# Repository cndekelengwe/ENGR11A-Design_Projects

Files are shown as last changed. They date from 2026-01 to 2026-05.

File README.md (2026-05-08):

# Automatic Pill Dispenser
## Overview 
**Possible limits: Needing a 3D Printer and Soldering machine** 

Our project addresses the challenge that older adults with dementia or memory-related conditions face when trying to manage their medications independently. Many struggle to remember when to take their pills or whether they have already taken them, which can lead to missed doses or double-dosing. Based on this, our needs statement is that users require a system that not only organizes their medication clearly but also supports them in taking the correct pills at the correct time without relying heavily on a caregiver. To guide our design, we focused on three main principles: simplicity, reliability, and automation. The device must be easy to understand and use, consistently perform without errors, and reduce the need for memory through automated assistance. Success for our design would mean that the device can accurately stop at the correct compartment every time, dispense the correct pills, and remain easy for users to load and interact with. We plan to measure this through testing stopping accuracy, consistency over repeated rotations, and how easily a user can interact with the system. If the device does not meet these expectations, we will adjust key elements such as compartment spacing, magnet placement, or control logic to improve performance.

## Final Design Challenges and Lessons Learned

Our final CAD design aimed to create a rotating pill dispenser system similar to a Ferris wheel, where a circular 15-compartment wheel rotated inside a rectangular support structure. The design included 14 compartments for daily and nightly medication and one additional compartment serving as a refill or reminder section. To automate positioning, magnets were embedded into the rotating inner section, while Hall sensors connected to an Arduino system were intended to detect the magnets and stop the wheel at the correct compartment. The overall goal was to create a system that could reliably organize and dispense medication while supporting user independence and reducing medication errors.

However, during testing and evaluation of the final design, we encountered a major issue with the sensor-detection system. Because the wheel continuously rotated, the Hall sensors were not consistently able to detect every magnet as intended. Some magnets were detected successfully, while others were missed depending on alignment, spacing, and distance during rotation. This created an inconsistency in stopping accuracy, which reduced the reliability of the dispensing mechanism. As a result, although the design successfully demonstrated the overall concept and functionality of the system, the final STL design was not fully reliable in practice and would require additional redesign iterations before being used as a dependable automated dispenser.

One major lesson learned from this project was the importance of sensor placement and detection range in rotating automated systems. For future improvements, we would recommend using larger magnets and increasing the overall scale of the design to improve the consistency of Hall sensor detection. Increasing spacing and improving alignment tolerance between components would likely make the stopping mechanism more reliable and improve overall system performance.

Below are the STL files for the final design in case anyone would like to experiment with or improve upon the project further. We also made the different design iterations and cycles public so others can see the progression of the project from early concepts to the final design. All CAD files, iterations, and design changes can be found on Onshape through the link attached below. Onshape is free to use, making it accessible for anyone interested in viewing, modifying, or building upon the project.

[Rectangular Outlier Box File ](https://github.com/cndekelengwe/ENGR11A-Design_Projects/blob/main/pill_dispenser/Rectangular%20box.stl)  
[Wheel Compartements for pills STL File ](https://github.com/cndekelengwe/ENGR11A-Design_Projects/blob/main/pill_dispenser/cycle%203%20-%20Part%201%20(1).stl)  
[Drop box](https://github.com/cndekelengwe/ENGR11A-Design_Projects/blob/main/pill_dispenser/drop%20box%20-%20Part%201.stl)  
[ONshape Public File](https://cad.onshape.com/documents/309217a32cb4d046a7bca957/w/9944779888e9e89e632aefbe/e/01b1d22fc2a453b275cd808a)  (PS - if the link is unclickable, then copy the link and paste in the search bar) 

## Step-by-Step Circuit Assembly Guide for the Automatic Pill Dispenser
**Necessary Items** 

Download Arduino or any compatible coding platform for arduino board. 

A small breadboard (you can use basically any breadboard as long as it accommodates the necessary design size) 

A couple of different jumper wires - link

A USB Printer Cable

An LED (depending on how much light you want,  get as many LEDs).

A motor - Gebildet 8pcs DC3V-12V DC Geared Motor, for Aircraft Toys/Robotic Body/Four-Wheel Drive Toy Car, Batch Number: Double Axis 1:48

2 regular wires
A soldering machine is not needed, but is suggested; it is commonly found in a library. 

A cable to connect the battery 

Resistor (higher than 222 ohms) 

A 9V battery clip

DRV8833 Dual H-Bridge DC Motor Driver Module H

Link for Recommended Purchases - https://docs.google.com/document/d/1mJEsCzdOZILXJwwprC4P9GmpTi7Cr48AwGSw3bIJmXU/edit?tab=t.0 

**Step-By_Step Processs For Code and Circuit** 

1. For every Hall sensor, use male-to-female jumper wires to connect them to the Hall sensor and buzzer, remembering which wire colors go where (look at the picture for reference). <p align="center">
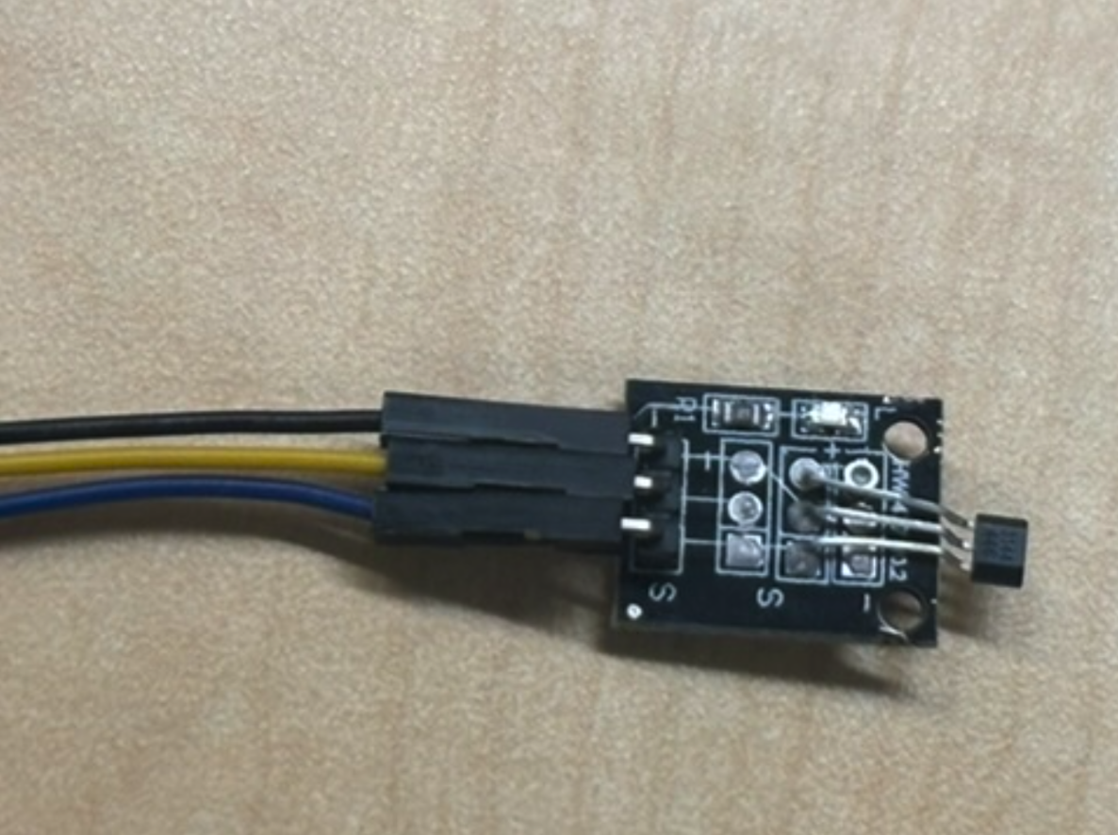
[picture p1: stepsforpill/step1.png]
   </p>
2. Now connect the blue jumper wire (or whatever color you used) to the corresponding pin numbers (2, 3, 4, 5), and connect the purple jumper wire (buzzer) to pin number 6.<p align="center">
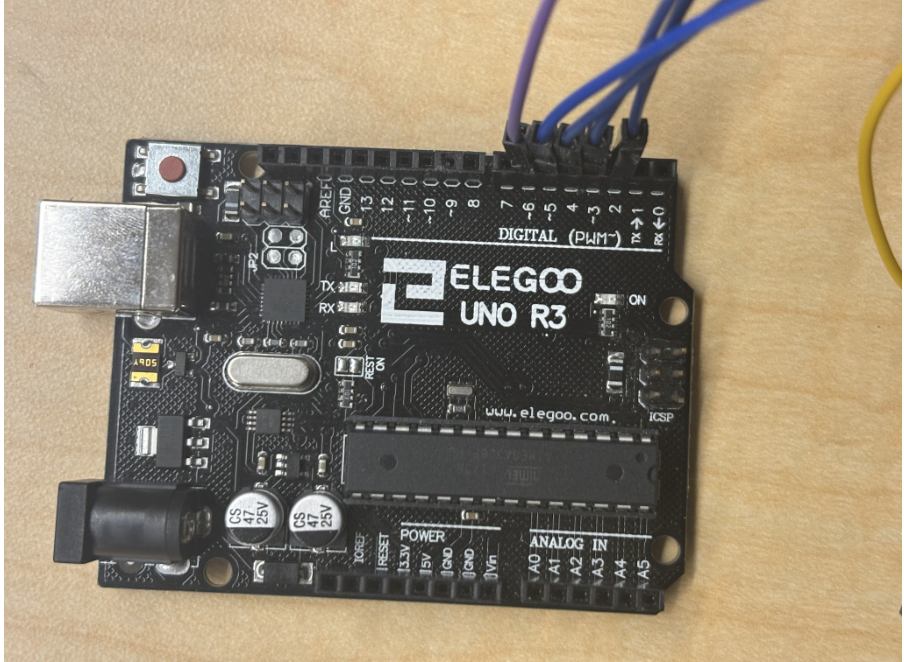
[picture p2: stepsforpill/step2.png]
   </p> 
3. Then, using the breadboard, align all the yellow jumper wires (power) on a single row and the black jumper wires (ground) on the row below.<p align="center">
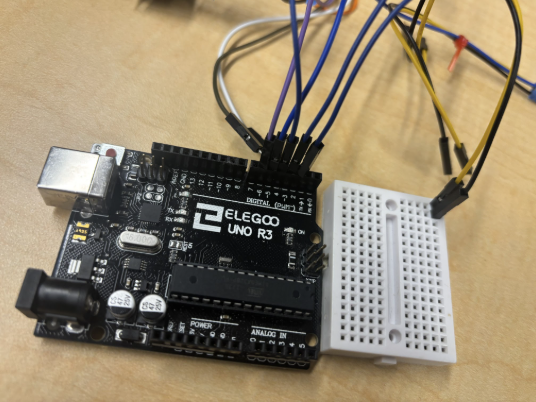
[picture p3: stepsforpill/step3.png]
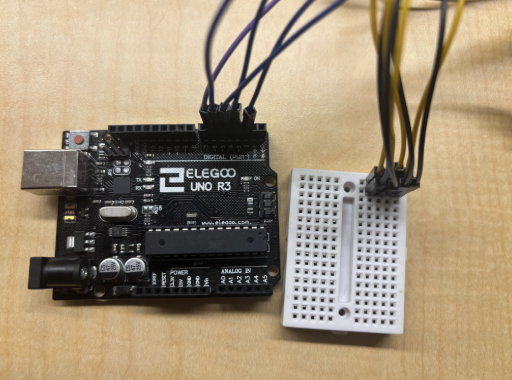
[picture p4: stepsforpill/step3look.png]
    </p>
4. If using the small breadboard, use two male-to-male wires to connect each row to the corresponding row next to it.<p align="center">
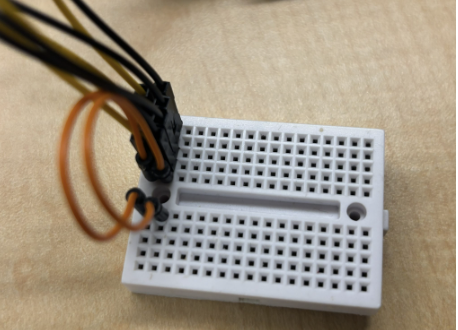
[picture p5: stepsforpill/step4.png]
   </p>
5. Then connect the corresponding buzzer cable to power and ground. (In this case, power was connected through a white jumper cable and ground through a brown cable.)<p align="center">
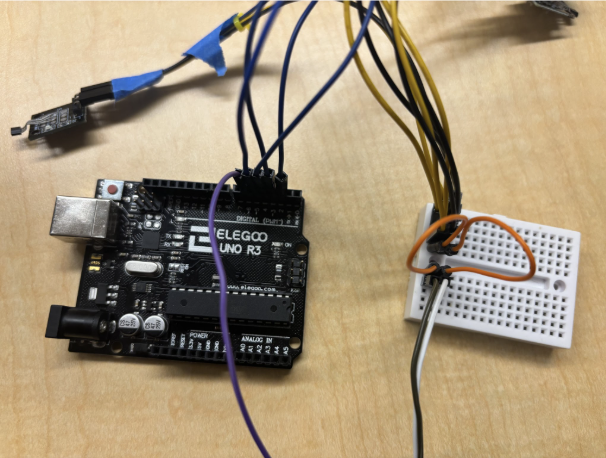
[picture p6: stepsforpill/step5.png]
   </p>
6. Next, use male-to-male wires to connect one wire from the 5V pin on the Arduino board to the power row on the breadboard. Then connect another wire from the GND pin on the Arduino board to the corresponding ground row on the breadboard. (Red is power and green is ground.)<p align="center">
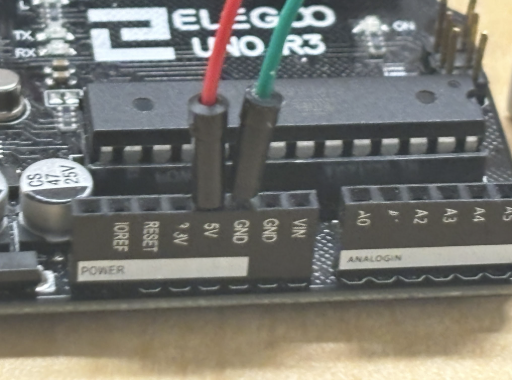
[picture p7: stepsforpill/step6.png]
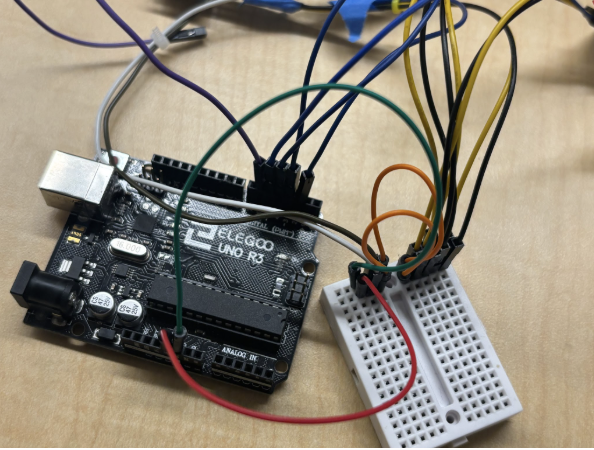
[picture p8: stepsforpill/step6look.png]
    </p>
7. Then move on to the Dual H-Bridge; connect IN1 and IN2 to the corresponding pin numbers on the Arduino board, which are pins 10 and 11. <p align="center">
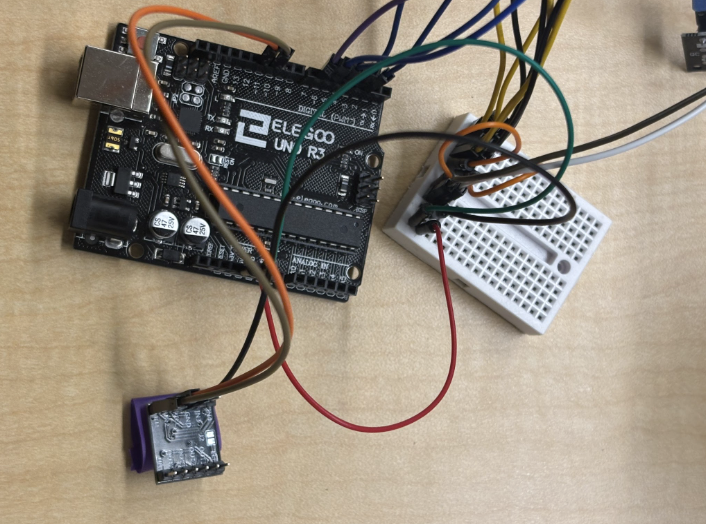
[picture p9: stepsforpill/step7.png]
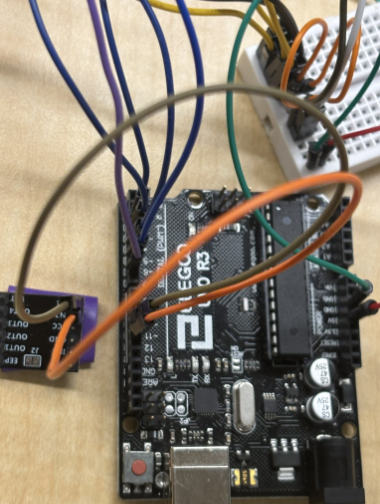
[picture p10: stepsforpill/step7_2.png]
    </p>
8. Using another male-to-female connector, connect GND from the Dual H-Bridge to one of the spaces on the GND row of the breadboard.
9. Then, using 2 wires, carefully strip part of the insulation and wrap the exposed wire around the small flaps at the tip of the motor wire. Bonus points if you solder them together for a stronger connection.<p align="center">
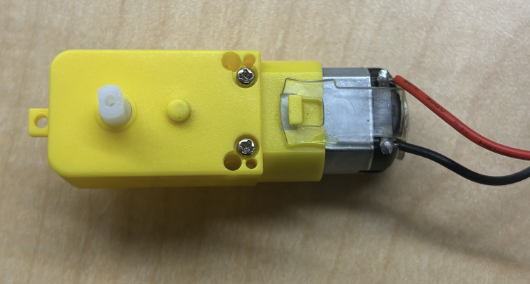
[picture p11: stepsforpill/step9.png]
   </p>
10. Then use two female-to-female wires to connect the wires to OUT1 and OUT2, connecting the motor to the circuit. (It does not matter which wire goes where; it only determines the direction the motor spins.)<p align="center">
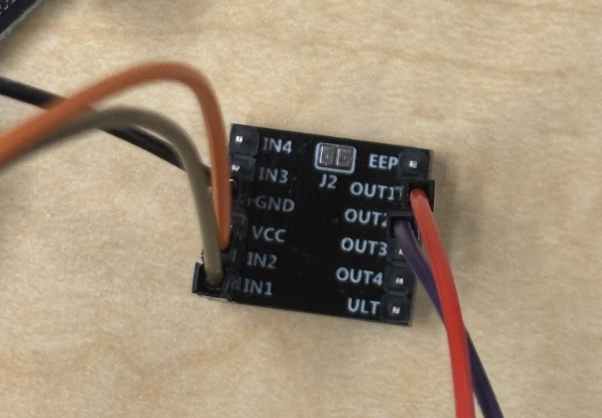
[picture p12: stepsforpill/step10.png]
    </p>
11. Use an additional male-to-male wire to connect the designated ground row on the breadboard to an additional row on the breadboard (look at the image for an example; it is the blue wire).<p align="center">
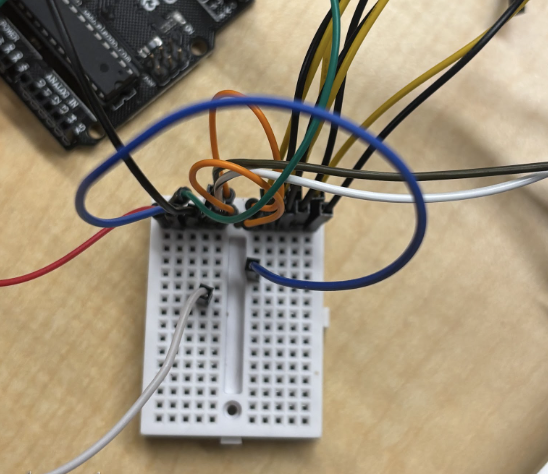
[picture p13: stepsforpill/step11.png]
   </p>
12. Then connect the black wire of the 9V battery clip to the row connected to the GND of the Arduino board.
13. Using a male-to-female connector, connect the pin labeled EEP on the breadboard, then connect the red wire from the battery clip to it. <p align="center">
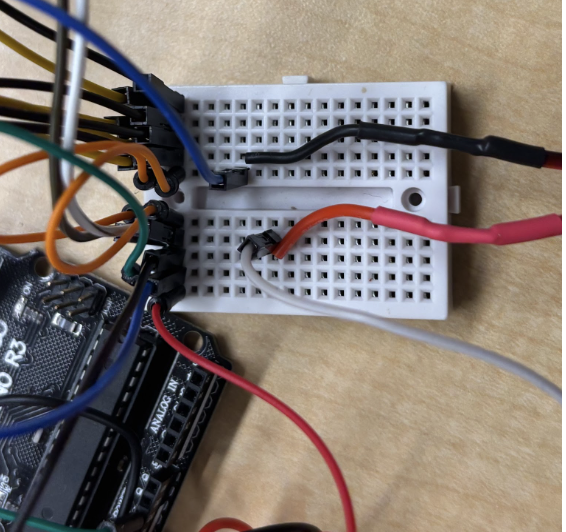
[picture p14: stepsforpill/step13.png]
   </p>
14. To connect the LED, use a male-to-male connector to connect the LED pin number (in this case, pin 13) to an empty row on the breadboard. (This allows multiple LEDs to share the same pin without requiring additional programming or extra pin numbers.) <p align="center">
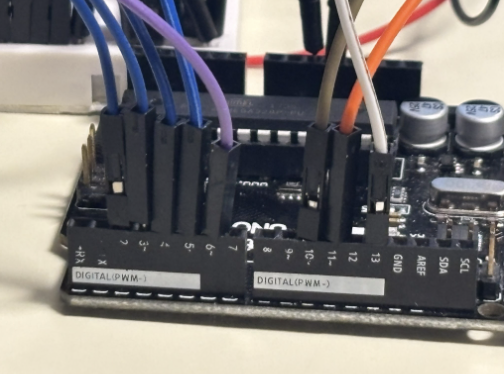
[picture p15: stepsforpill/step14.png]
   </p>
15. Connect both LED pins to male-to-female jumper wires, making sure to remember which wire is connected to which leg. This gives the LEDs more flexibility in placement. <p align="center">
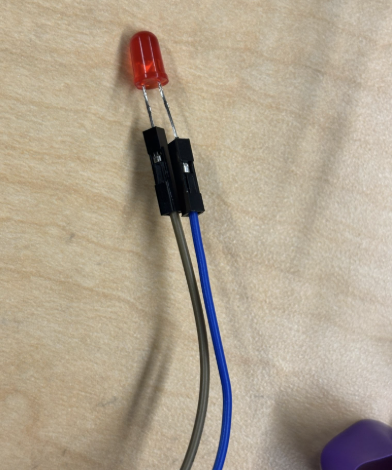
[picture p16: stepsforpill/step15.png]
   </p> In this case, the blue wire is the longer leg of the LED, and the black wire is the shorter leg.
16. Then take a resistor and place one leg of the resistor into the row connected to the LED pin number and the other leg into the designated ground row on the breadboard. <p align="center">
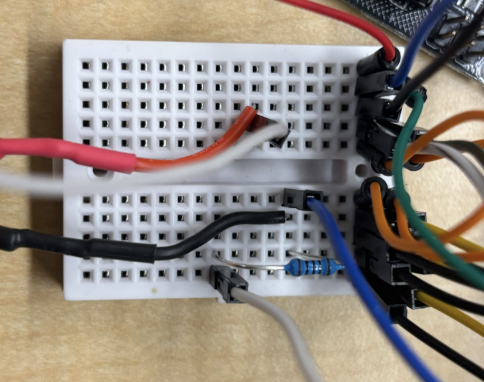
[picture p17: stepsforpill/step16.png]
   </p>
17. Finally, connect the LED to both the designated ground row and the LED row. Connect the shorter leg (cathode) to the GND row and the longer leg (anode) to the row connected to the LED pin number.
18. After completing all circuit connections, connect the Arduino board to a computer using a USB cable.
19. Open the Arduino IDE and upload the pill dispenser code to the Arduino board. Make sure the correct board type and COM port are selected before uploading. The board should be the same, but the port (circle in blue) depends on your computer <p align="center">
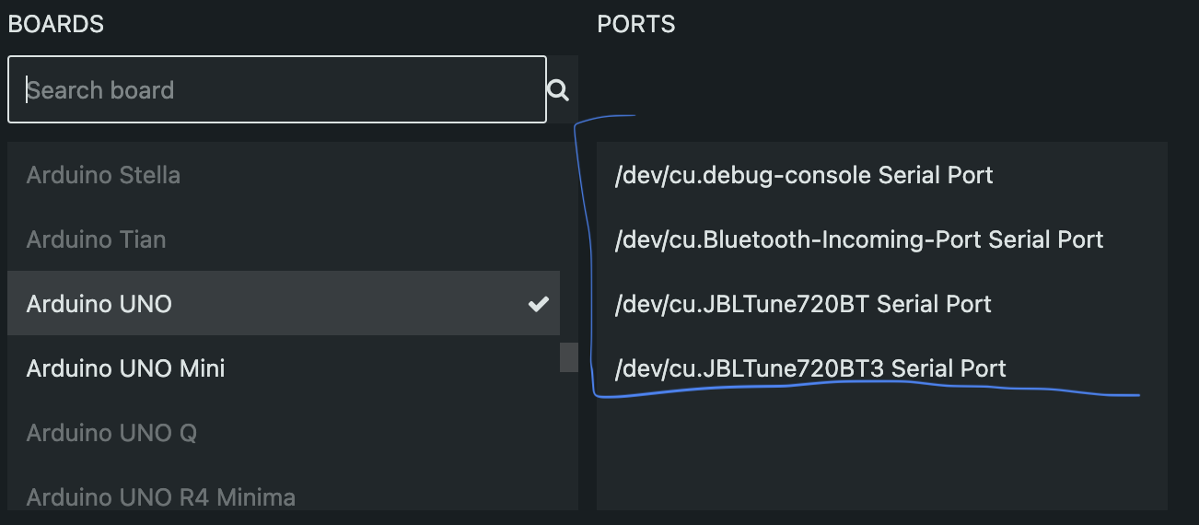
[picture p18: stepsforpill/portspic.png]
   </p>
20. Connect the 9V battery to the battery clip to power the system (for the H-board). The Hall sensors, LEDs, buzzer, and motor should now receive power through the circuit. (PS - in the complete picture, the blue drawing shows where the first battery connecting to the H-board goes) 
21. Test the system by checking whether the Hall sensors correctly detect the magnets and stop the motor at the intended compartment positions. Also, verify that the LEDs and buzzer respond correctly. PS - the motor should always be spinning, stop when it sees a magnet, which is followed by the buzzer and LED lighting. Then, depending on the time chosen (the default time being 20 seconds), it will start spinning after that.
22. If the system does not behave as expected, recheck all wiring connections, sensor alignment, magnet placement, and uploaded code. Small changes in spacing or alignment may significantly affect Hall sensor detection accuracy.
23. Once the system works as needed, disconnect the Arduino board from the computer. Plug in the second battery in the Arduino board. (PS - in the complete picture, the pink drawing shows where the second battery connecting to the Arduino board goes) 
24. Once testing is complete and the system functions correctly, secure loose wires and components to improve the stability and reliability of the final setup. <p align="center">
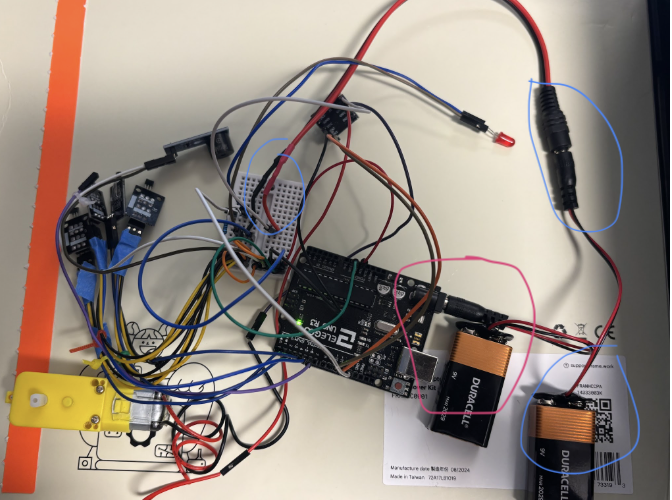
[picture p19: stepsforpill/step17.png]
   </p>

**Step-By_Step Processs For CAD with ONshape** 
1. Print the Final Cycle Outer Box <p align="center">
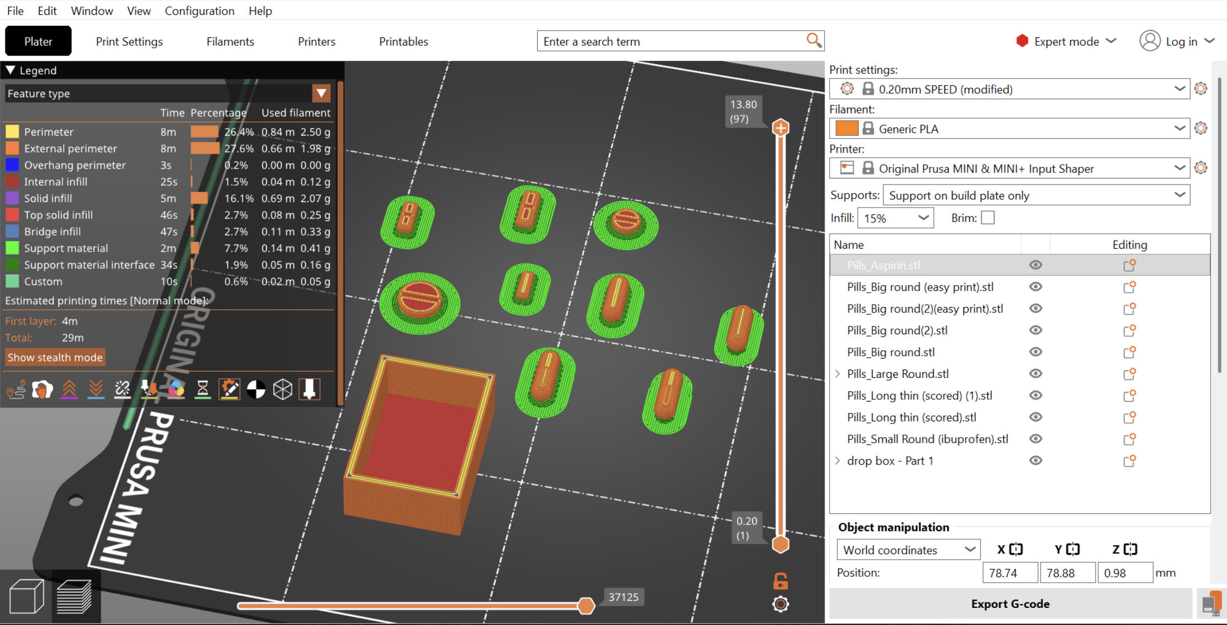
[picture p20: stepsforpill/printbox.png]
   </p>
2. Print the Final Cycle Wheel <p align="center">
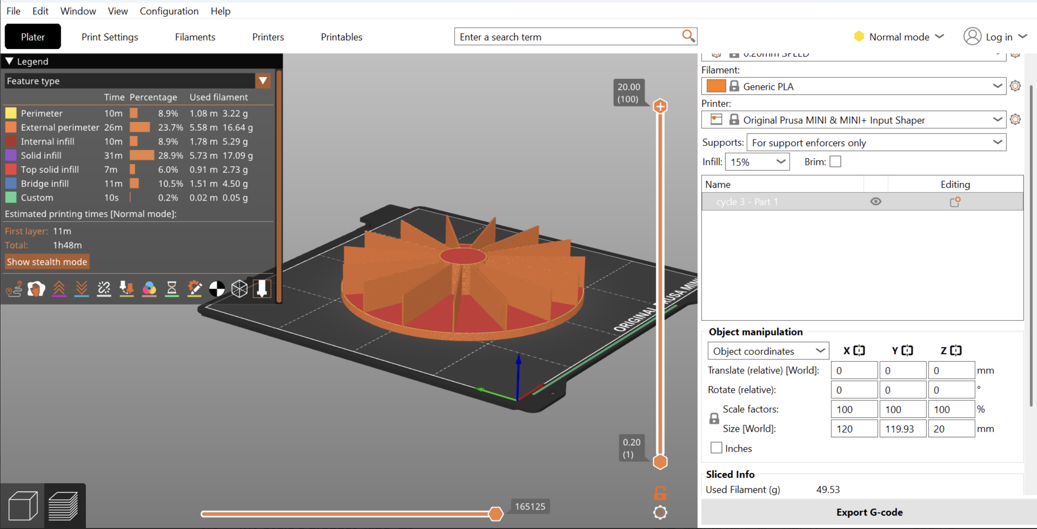
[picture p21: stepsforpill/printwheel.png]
   </p>
3. Print the Final Cycle Medicine Tray<p align="center">
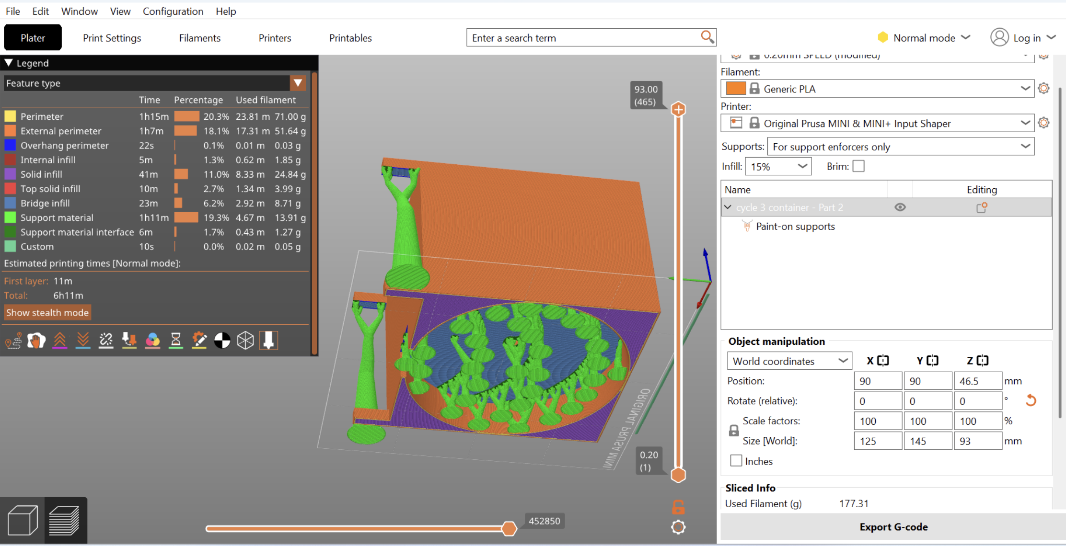
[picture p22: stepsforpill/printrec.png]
   </p>
4. Either print and customize a door to go with design.  Or use clear Acrylic as shown in the picture.<p align="center">
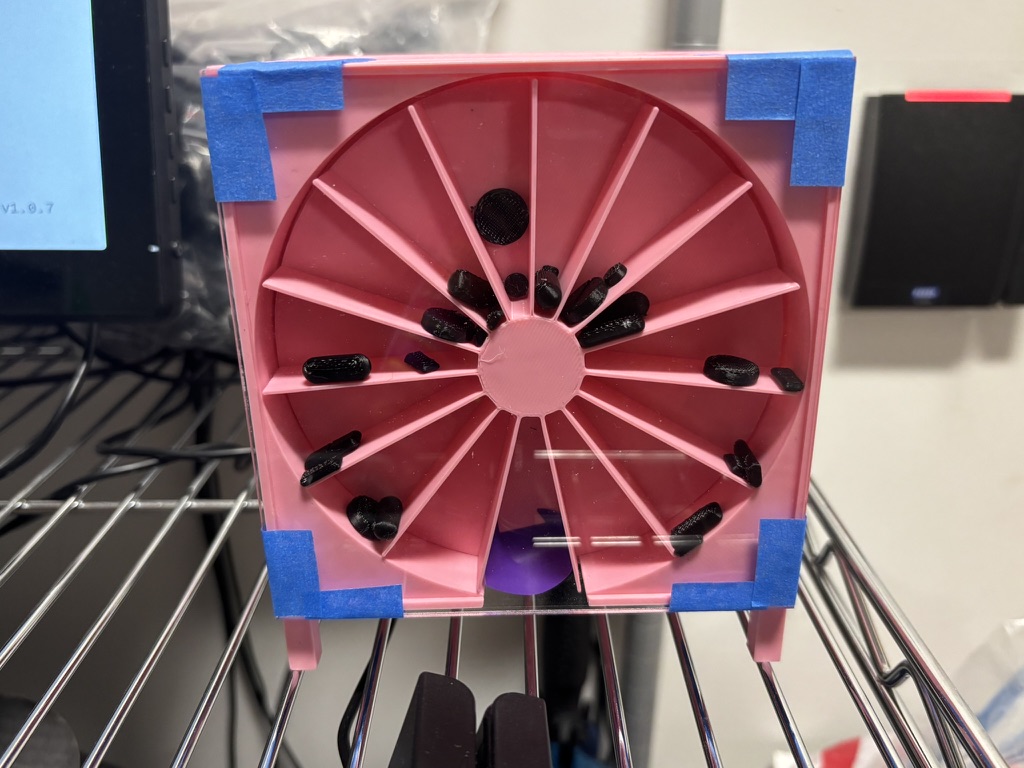
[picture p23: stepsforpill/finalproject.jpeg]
   </p>

**Suggested Steps Forward***
1. Use Larger and Stronger Magnets - One of the biggest issues we encountered was inconsistent Hall sensor detection. Using larger or stronger magnets would improve detection reliability and reduce missed positions.
2. Increase the Overall Scale of the Design - The design became too compact, making alignment between the Hall sensors and magnets difficult. A slightly larger wheel and spacing between components would improve consistency and make assembly easier.
3. Continue Iterative Testing Before Final Assembly - Test the motor, sensors, and wheel alignment separately before fully assembling the final design. Small issues become much harder to troubleshoot once everything is integrated together. And finally, good luck with the design.
   
Link to a presentation recording about our process:
https://drive.google.com/file/d/1EsrDOxK41wTlbXEBnxdr2zpXb8wZuB0q/view?usp=sharing 

Link to code used - https://docs.google.com/document/d/1jkpZ4H0KWvsoafJ_Ff6-uf_Do_P35tXl_jxYF_B4JnI/edit?tab=t.nf3fixb14pqj

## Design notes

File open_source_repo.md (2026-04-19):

<!DOCTYPE html>
<!-- saved from url=(0047)https://gleverette.github.io/ENGR11A/prusa.html -->
<html lang="en">
    <head>
        <meta charset="utf-8" />
        <meta name="viewport" content="width=device-width, initial-scale=1, shrink-to-fit=no" />
        <meta name="description" content="" />
        <meta name="author" content="" />
        <title>Cycle Iterations</title>
        <!-- Favicon-->
        <link rel="icon" type="image/x-icon" href="assets/icon.jpg" />
        <!-- Custom Google font-->
        <link rel="preconnect" href="https://fonts.googleapis.com" />
        <link rel="preconnect" href="https://fonts.gstatic.com" crossorigin />
        <link href="https://fonts.googleapis.com/css2?family=Plus+Jakarta+Sans:wght@100;200;300;400;500;600;700;800;900&amp;display=swap" rel="stylesheet" />
        <!-- Bootstrap icons-->
        <link href="https://cdn.jsdelivr.net/npm/bootstrap-icons@1.8.1/font/bootstrap-icons.css" rel="stylesheet" />
        <!-- Core theme CSS (includes Bootstrap)-->
        <link href="css/styles.css" rel="stylesheet" />
    </head>
    <body class="d-flex flex-column h-100" style="background-color: #f6f1e7;">
        <main class="flex-shrink-0">
            <!-- Navigation-->
            <nav class="navbar navbar-expand-lg navbar-light py-3">
                <div class="container px-5">
                    <a class="navbar-brand" href="index.html">
                        <span class="fw-bolder" style="color: #B109C8;">Portfolio</span>
                    </a>
                    <button class="navbar-toggler" type="button" data-bs-toggle="collapse" data-bs-target="#navbarSupportedContent" aria-controls="navbarSupportedContent" aria-expanded="false" aria-label="Toggle navigation"><span class="navbar-toggler-icon"></span></button>
                    <div class="collapse navbar-collapse" id="navbarSupportedContent">
                        <ul class="navbar-nav ms-auto mb-2 mb-lg-0 small fw-bolder">
                            <li class="nav-item"><a class="nav-link" href="index.html" style="color: #B109C8;">Home</a></li>
                            <li class="nav-item"><a class="nav-link" href="resume.html" style="color: #B109C8;">Resume</a></li>
                            <li class="nav-item"><a class="nav-link" href="projects.html" style="color: #B109C8;">Projects</a></li>
                            <li class="nav-item"><a class="nav-link" href="contact.html" style="color: #B109C8;">Contact</a></li>
                        </ul>
                    </div>
                </div>
            </nav>
        
          <h2 style="font-family: 'Nunito'; font-weight: bold; text-align:center; padding-top:30px; color: #B109C8;">
          Cycle Process for Timed Pill Dispenser
          </h2>

                <div style="max-width: 1100px; margin: 0 auto; text-align: justify; padding: 0 10px; color: #102c4f;
                  font-family: 'Times New Roman', Times, serif;">

                  <h5 style="color: #AE15EB;" >
                    Our project addresses the challenge that older adults with dementia or memory-related conditions face when trying to manage their medications independently. Many struggle to remember when to take their pills or whether they have already taken them, which can lead to missed doses or double dosing. Based on this, our needs statement is that users require a system that not only organizes their medication clearly but also supports them in taking the correct pills at the correct time without relying heavily on a caregiver. To guide our design, we focused on three main principles: simplicity, reliability, and automation. The device must be easy to understand and use, consistently perform without errors, and reduce the need for memory through automated assistance. Success for our design would mean that the device can accurately stop at the correct compartment every time, dispense the correct pills, and remain easy for users to load and interact with. We plan to measure this through testing stopping accuracy, consistency over repeated rotations, and how easily a user can interact with the system. If the device does not meet these expectations, we will adjust key elements such as compartment spacing, magnet placement, or control logic to improve performance.
                  </h5>
                  
                  <!--<h5 style="color: #4109B5;">
                    The files for this project can be accessed through platforms such as <a href="https://3d.nih.gov/collections/prosthetics">NIH 3D Print Exchange</a>  and <a href="https://www.thingiverse.com/thing:1453190">(click here for link)</a>. Overall, locating the files is relatively straightforward, as it mainly involves searching for the design on a 3D printing database. However, when it comes to selecting the correct parts, the process becomes more complicated. The files are not clearly grouped or organized by sections, which makes it difficult to confirm whether all necessary components have been downloaded. For example, during assembly, my group realized we were missing smaller parts such as the whippletree. While this was manageable for us since it was a quick reprint, in situations where time or resources are limited, this could create a more significant issue.

                  </h5>
                  <h5 style="color: #4109B5;"> 
                    When it came to assembling the hand, we initially followed the official instructions provided through the <a href="https://3d.nih.gov/collections/prosthetics">NIH website</a>, along with supplementary videos created by other groups. While these resources were helpful, the process was still somewhat difficult to follow. I found that watching the videos alone was not enough, as I often had to pause and rewatch sections multiple times while working. To improve my understanding, I referred to an alternative step-by-step guide <a href = "https://cdn.thingiverse.com/assets/dd/6b/45/30/fc/Phoenix_v2_assembly_guide.pdf">alternative step-by-step guide</a> that included more detailed explanations and visual references. Although it did not cover every small step, it was easier to follow because the visuals helped fill in the gaps between instructions. Overall, the design itself is fairly accessible, as it is divided into smaller components and does not require a large printer to produce.
                    </h5>
              </div> -->

               <h4 style="font-family: 'Nunito'; font-weight: bold; padding-top:10px; color: #B109C8;">
                    Cycle 1          </h4>
                    <div style="max-width: 1100px; margin: 0 auto; text-align: justify; padding: 0 10px; padding-top: 10px; color: #102c4f;
                font-family: 'Times New Roman', Times, serif;">
                <figure style="float: right; width: 300px; margin: 0 15px 15px 0; text-align: center;">

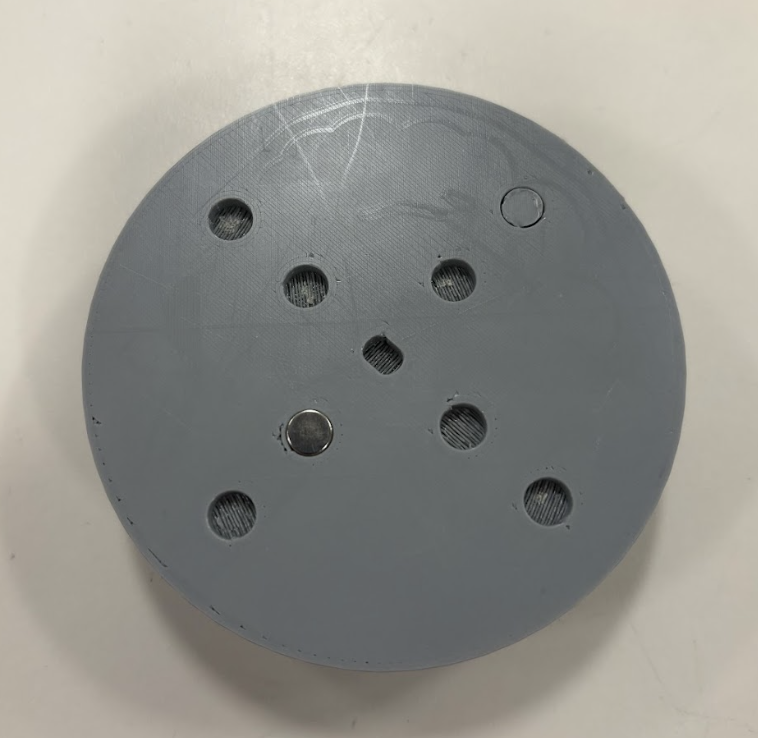
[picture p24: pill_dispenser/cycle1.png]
                  

                  <figcaption style="font-size: 0.85rem; margin-top: 6px; color: #7A40ED;">
                    Figure 1: Printed 3d protype
                  </figcaption>

                </figure>
                  <h5 style="color: #AE15EB;" > 
                        The goal of this cycle was to create a simple physical prototype to test the core concept of a rotating pill dispenser. We wanted to understand how a circular compartment system behaves in terms of movement, spacing, and ease of access before committing to a more complex design.            
                        <ul style="list-style-type: circle;"> 
                            <li>Design initial compartment model in CAD </li>
                            <li> Keep design simple for fast prototyping</li>
                            <li>Observe structural stability and usability</li>
                            <li> Test rotation and accessibility of compartments</li>
                      </li>
                  </ul>
                 <strong> What We Actually Accomplished :</strong> We built a 4-compartment prototype to quickly test the idea without overcomplicating the design. This helped us confirm that a rotating system is practical and that users can access compartments easily. However, it also showed that fewer compartments limit functionality and that alignment between sections needs to be precise. This means our design direction is valid, but requires more compartments and improved accuracy for real use.
              </h5>

              <h4 style="font-family: 'Nunito'; font-weight: bold; padding-top:10px; color: #B109C8;">
                    Cycle 2 </h4>

                    <div style="max-width: 1100px; margin: 0 auto; text-align: justify; padding: 0 10px; padding-top: 10px; color: #102c4f;font-family: 'Times New Roman', Times, serif;">
                <figure style="float: right; width: 300px; margin: 0 15px 15px 0; text-align: center;">

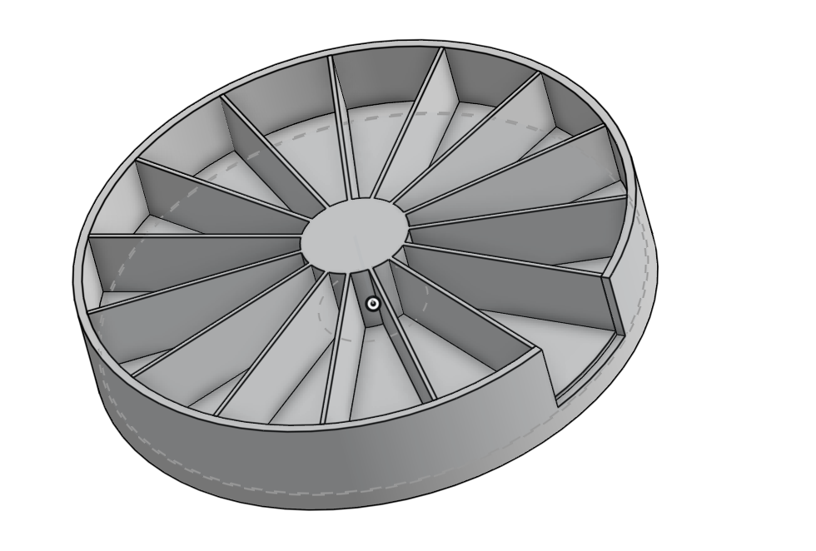
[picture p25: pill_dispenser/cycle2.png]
                  

                  <figcaption style="font-size: 0.85rem; margin-top: 6px; color: #7A40ED;">
                    Figure 2: Final 3d Design for pill dispenser
                  </figcaption>

                </figure>
                  <h5 style="color: #AE15EB;" > 
                    The goal of this cycle was to refine the design by expanding it into a full 15-compartment system, while also planning for features like day/night separation and a refill section. We also aimed to incorporate a stopping mechanism into the structure itself.
                        <ul style="list-style-type: circle;"> 
                            <li>Redesign model with 15 compartments </li>
                            <li>Include center section for magnet placement</li>
                            <li>Ensure equal spacing for accurate rotation</li>
                            <li> Evaluate design feasibility</li>
                      </li>
                  </ul>
                 <strong> What We Actually Accomplished :</strong> We completed a detailed 15-compartment CAD design with evenly spaced sections and a designated refill slot. We also added central holes for magnets, which are critical for controlling where the system stops. While it hasn’t been printed yet, this step is important because it translates the concept into a design that can support automation and precise positioning.
              </h5>
                     
            <h4 style="font-family: 'Nunito'; font-weight: bold; padding-top:10px; color: #B109C8;">
                    Cycle 3          </h4>
                    <div style="max-width: 1100px; margin: 0 auto; text-align: justify; padding: 0 10px; padding-top: 10px; color: #102c4f;
                font-family: 'Times New Roman', Times, serif;">
                <figure style="float: right; width: 300px; margin: 0 15px 15px 0; text-align: center;">

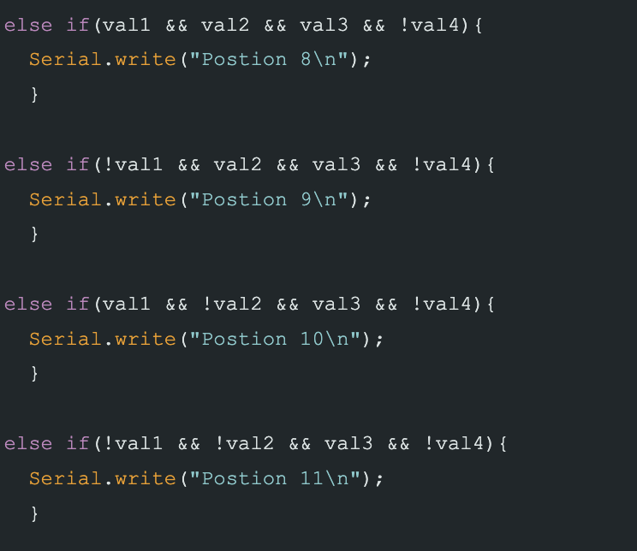
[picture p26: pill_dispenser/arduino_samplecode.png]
                  

                  <figcaption style="font-size: 0.85rem; margin-top: 6px; color: #7A40ED;">
                    Figure 3: Arduino sample code
                  </figcaption>

                </figure>
                  <h5 style="color: #AE15EB;" > 
                       The goal of this cycle was to develop and validate the control system that will allow the pill maker to stop at the correct compartment. This involved creating an Arduino-based mechanism that can detect magnets and use that signal to control motion, ensuring accurate positioning for dispensing.
            
                        <ul style="list-style-type: circle;"> 
                            <li>Write Arduino code for magnet detection</li>
                            <li> Test sensor response to magnets</li>
                            <li>Integrate stopping logic into code</li>
                            <li> Prepare motor connection setup</li>
                            <li> Test system behavior (code + detection) </li>

                  </ul>
                 <strong> What We Actually Accomplished :</strong> We developed Arduino code that successfully detects the presence of a magnet and triggers a stop condition. This is a critical step because it establishes how the system will know when it has reached the correct compartment. Although the code has not yet been physically connected to the motor, it confirms that our approach to position control is viable. This directly supports the overall design by ensuring that each compartment can be aligned consistently, which is necessary for reliable dispensing.
              </h5>

            <h4 style="font-family: 'Nunito'; font-weight: bold; padding-top:10px; color: #B109C8;">
                    Cycle 4          </h4>
                   <!--< <div style="max-width: 1100px; margin: 0 auto; text-align: justify; padding: 0 10px; padding-top: 10px; color: #102c4f;
                font-family: 'Times New Roman', Times, serif;">
                <figure style="float: right; width: 300px; margin: 0 15px 15px 0; text-align: center;">

                  <img src="./IMG_7763.jpg"
                       alt="Completed design"
                       class="rounded shadow"
                       style="width: 250px; height: 300px; object-fit: cover; cursor: pointer;">

                  <figcaption style="font-size: 0.85rem; margin-top: 6px; color: #7A40ED;">
                    Figure 1: Both main ideas sketched out
                  </figcaption>
              </figure> -->
                  <h5 style="color: #AE15EB;" > 
                        The goal of this cycle is to integrate all components into a complete working system and evaluate its real-world performance. This includes assembling the 15-compartment model, connecting the motor and Arduino system, and testing how accurately and reliably the device rotates and stops at each compartment.            
                        <ul style="list-style-type: circle;"> 
                            <li>3D print final 15-compartment model</li>
                            <li>Insert magnets into center holes</li>
                            <li>Assemble motor with rotating base</li>
                            <li>Connect Arduino to motor system</li>
                            <li>Test full rotation and stopping accuracy</li>
                            <li>Evaluate durability and material performance</li>

                  </ul>
                 <strong> What We Actually Accomplished :</strong> This cycle is not fully completed yet, but significant progress has been made toward integration. We have a finalized design, a working detection system, and a clear assembly plan. The remaining step is to physically connect the motor and test the system in motion. Completing this cycle will allow us to verify if the design works as intended under real conditions, particularly in terms of stopping accuracy, consistency, and durability, which are essential for the device to function as a dependable pill dispenser.
              </h5>

<h4 style="font-family: 'Nunito'; font-weight: bold; padding-top:10px; color: #B109C8;">
                    How the Design Solves the Problem </h4>
<h5  style="color: #AE15EB;">
Our design was built from the ground up to directly reflect these needs and principles. The pill maker features a 15-compartment rotating system, with 14 compartments designated for daily and nightly medications and one additional compartment serving as a refill or reminder section. This structure allows users to organize their medication clearly over a full cycle, reducing confusion and supporting routine. To address reliability, we designed the inner core to include precisely placed magnets, which work with an Arduino-controlled sensor to detect position and stop the rotation at the correct compartment. This ensures that the system can consistently align with the intended section for dispensing. The use of a motor to drive rotation introduces automation, allowing the device to move on its own rather than relying on the user to manually track positions. Additionally, the circular layout promotes ease of access and intuitive use, as each compartment follows a predictable sequence. Together, these features create a system that not only organizes medication but actively supports correct usage, helping users maintain independence while reducing the risk of errors. </h5>

         <!-- Bootstrap CSS -->
<link href="https://cdn.jsdelivr.net/npm/bootstrap@5.3.2/dist/css/bootstrap.min.css" rel="stylesheet">

<style>
/* Style for the clickable heading */
.clickable-heading {
  color: #35AAF0;
  font-weight: bold;
  background-color: #F6F1E7;
    font-family: "Times New Roman", Times, serif;
  text-decoration: underline;
  cursor: pointer;
  transition: color 0.3s, text-decoration 0.3s;
}

/* Hover effect */
.clickable-heading:hover {
  color: #35AAF0;
  background-color: #F6F1E7;
  text-decoration: none;
}
/* Modal background and font */
.modal-content {
  background-color: #F6F1E7;
  font-family: "Times New Roman", Times, serif;
  color: #256E99;
}
</style>

<!--<h5 class="clickable-heading"
    style="margin-left:100px;"
    data-bs-toggle="modal"
    data-bs-target="#pics">
    Click here to see settings of design
</h5> -->

<!-- Modal -->
<div class="modal fade" id="pics" tabindex="-1" aria-hidden="true">

  <div class="modal-dialog modal-lg modal-dialog-centered">

    <div class="modal-content">

      <div class="modal-header">
        <h5 class="modal-title">Settings</h5>
        <button type="button" class="btn-close" data-bs-dismiss="modal"></button>
      </div>

      <div class="modal-body text-center">

        <div class="row g-4">

          <div class="col-md-6">
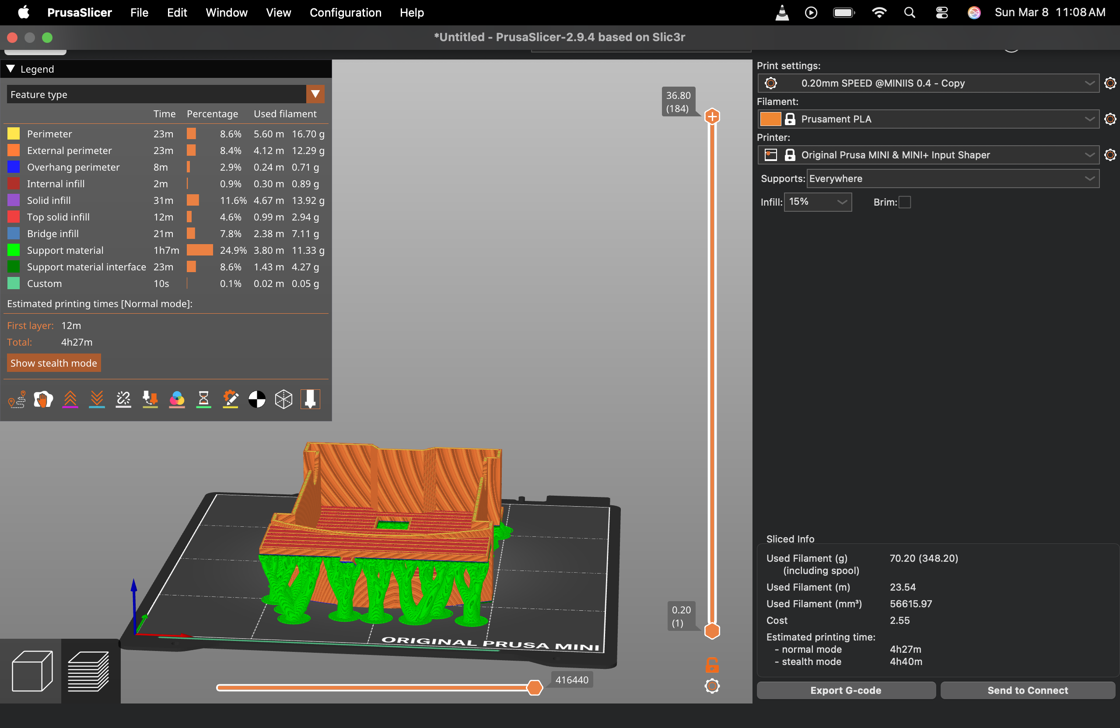
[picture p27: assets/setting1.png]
Failed Screw
            
            <p class="mt-2">Setting of Car design in PRUSA Slicer</p>
          </div>

          <div class="col-md-6">
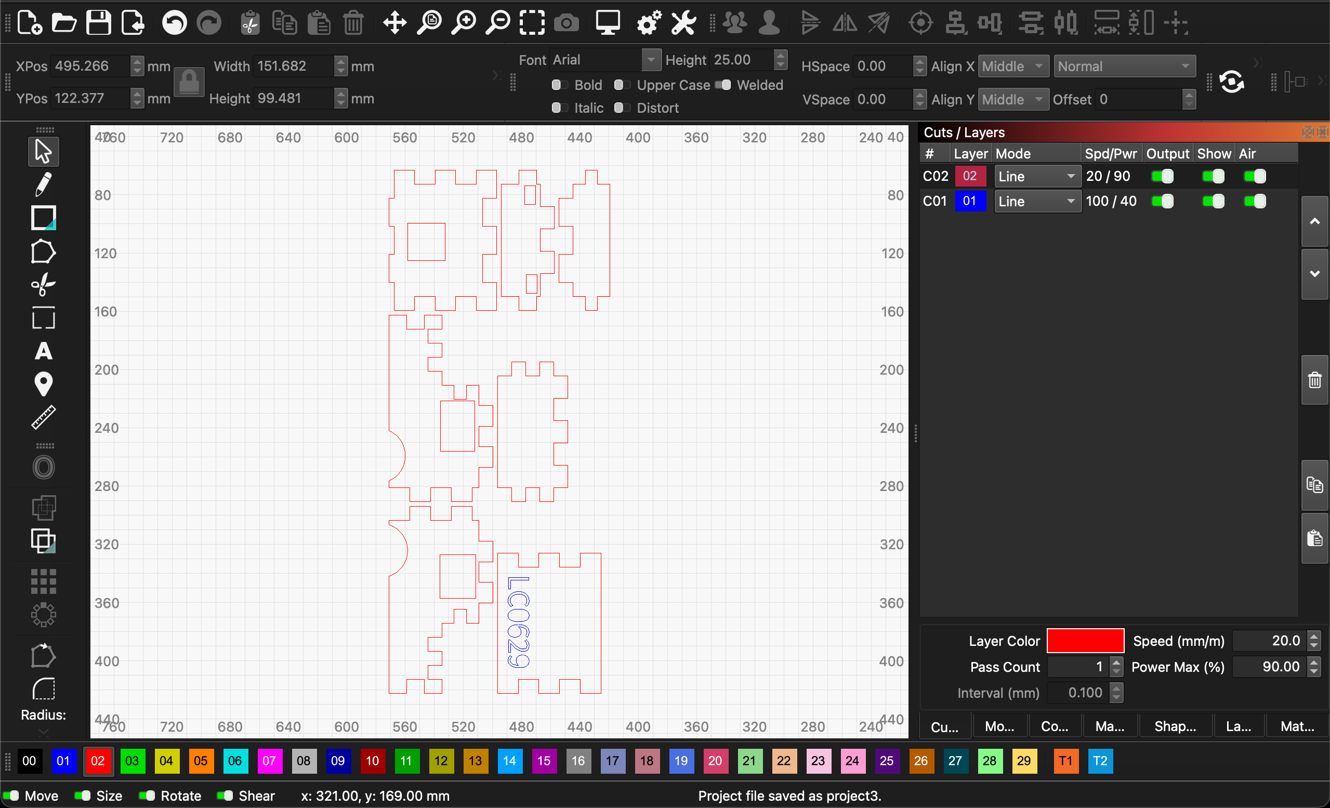
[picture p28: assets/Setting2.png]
Wheel
            
            <p class="mt-2">Setting of Car deign in LightBurn </p>
          </div>

          <div class="col-md-6">
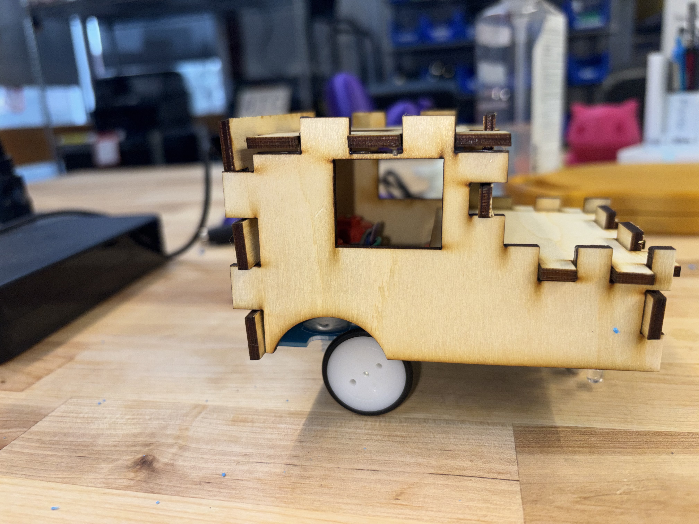
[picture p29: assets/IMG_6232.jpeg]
            
            <p class="mt-2">Laser Print Car Cover</p>
          </div>

          <div class="col-md-6">
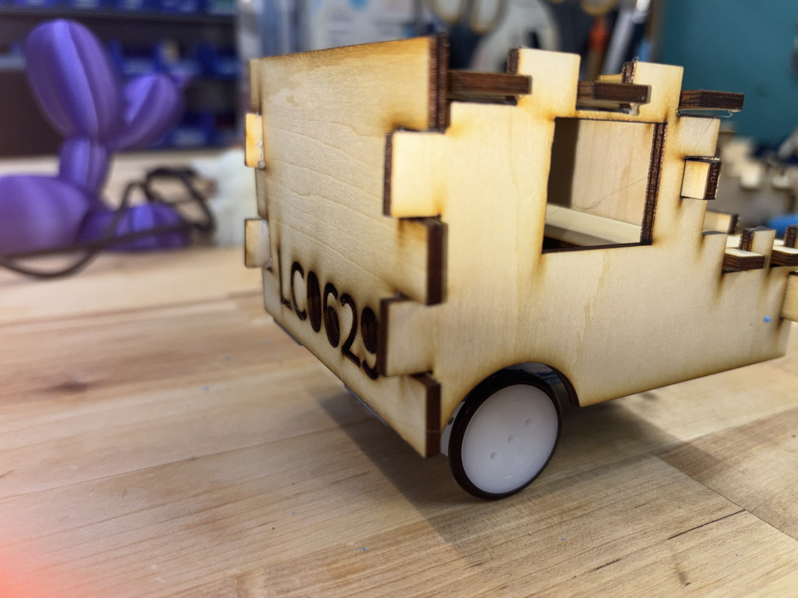
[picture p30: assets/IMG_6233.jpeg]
            
            <p class="mt-2">Laser Print Car Cover</p>
          </div>

        <div class="col-md-6 mx-auto">
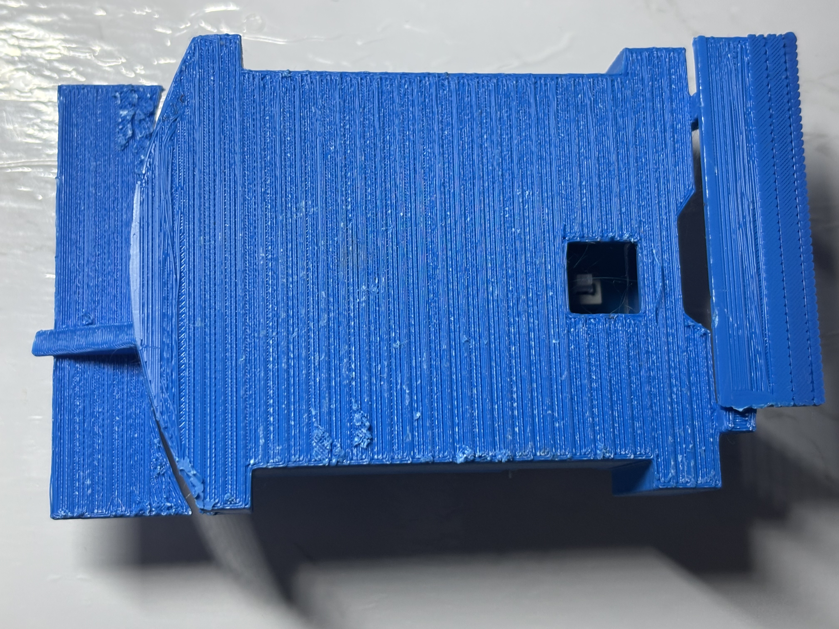
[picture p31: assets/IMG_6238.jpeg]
            
            <p class="mt-2">Result of UnderExtrusion</p>
          </div> 
        </div>

      </div>

    </div>

  </div>

</div>

<!-- Bootstrap JS -->
<script src="https://cdn.jsdelivr.net/npm/bootstrap@5.3.2/dist/js/bootstrap.bundle.min.js"></script>

        <main class="flex-shrink-0"> 

        </main></body><grammarly-desktop-integration data-grammarly-shadow-root="true"><template shadowrootmode="open"><style>
      div.grammarly-desktop-integration {
        position: absolute;
        width: 1px;
        height: 1px;
        padding: 0;
        margin: -1px;
        overflow: hidden;
        clip: rect(0, 0, 0, 0);
        white-space: nowrap;
        border: 0;
        -moz-user-select: none;
        -webkit-user-select: none;
        -ms-user-select:none;
        user-select:none;
      }

      div.grammarly-desktop-integration:before {
        content: attr(data-content);
      }
    </style></template></grammarly-desktop-integration></html>

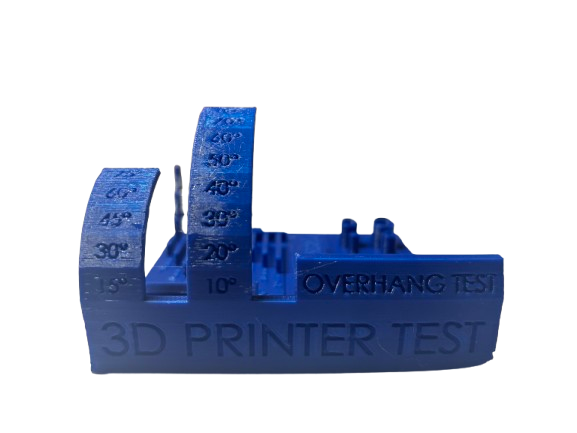
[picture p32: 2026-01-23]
assets/poster_pic_torture.png

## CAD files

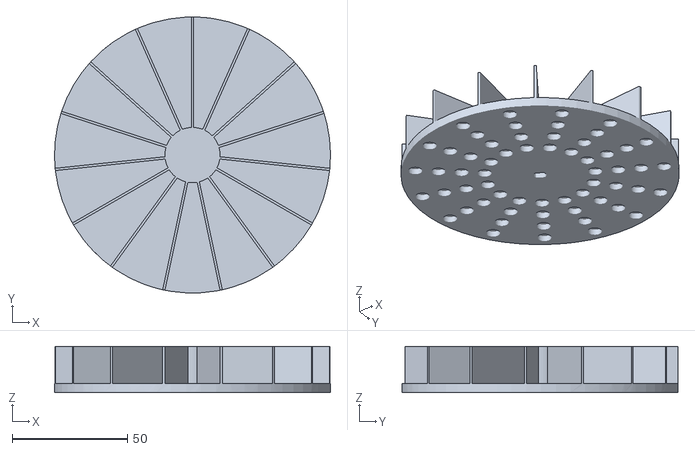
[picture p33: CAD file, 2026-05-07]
pill_dispenser/cycle 3 - Part 1 (1).stl
120.0 x 120.0 x 20.0

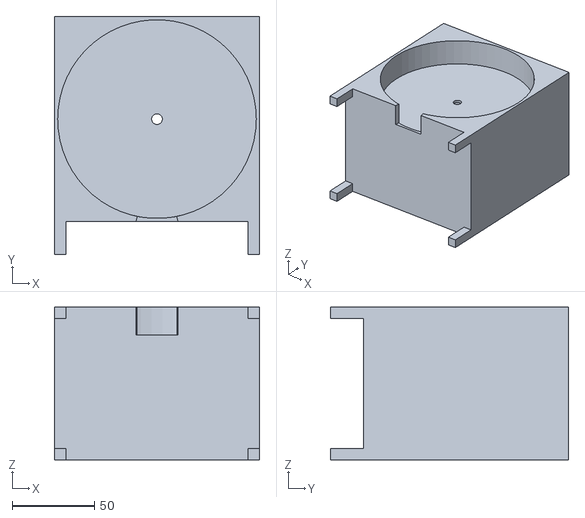
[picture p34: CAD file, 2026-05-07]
pill_dispenser/Rectangular box.stl
125.0 x 145.0 x 93.0

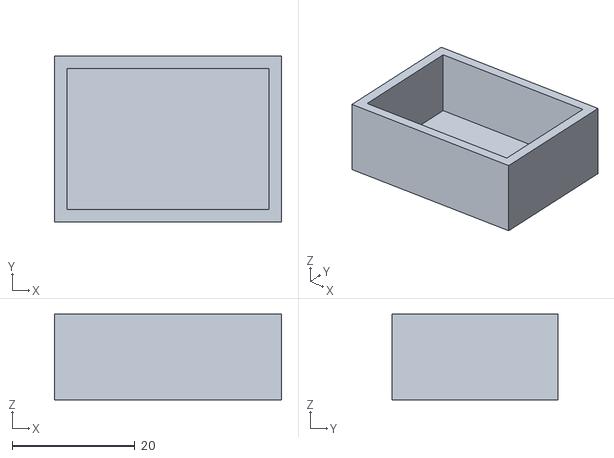
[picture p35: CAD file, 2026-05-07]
pill_dispenser/drop box - Part 1.stl
37.0 x 27.0 x 14.0

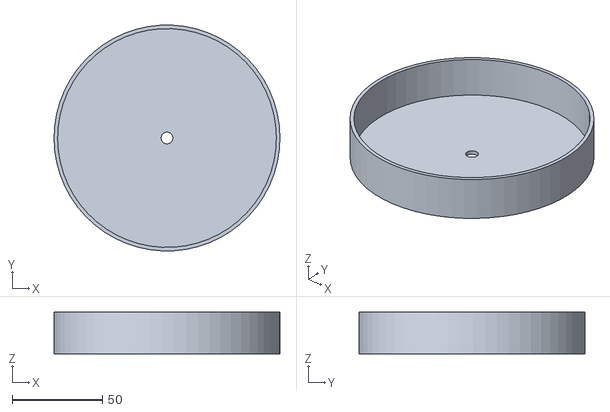
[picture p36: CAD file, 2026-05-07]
pill_dispenser/cycle 3 - Part 2.stl
125.0 x 124.9 x 23.0

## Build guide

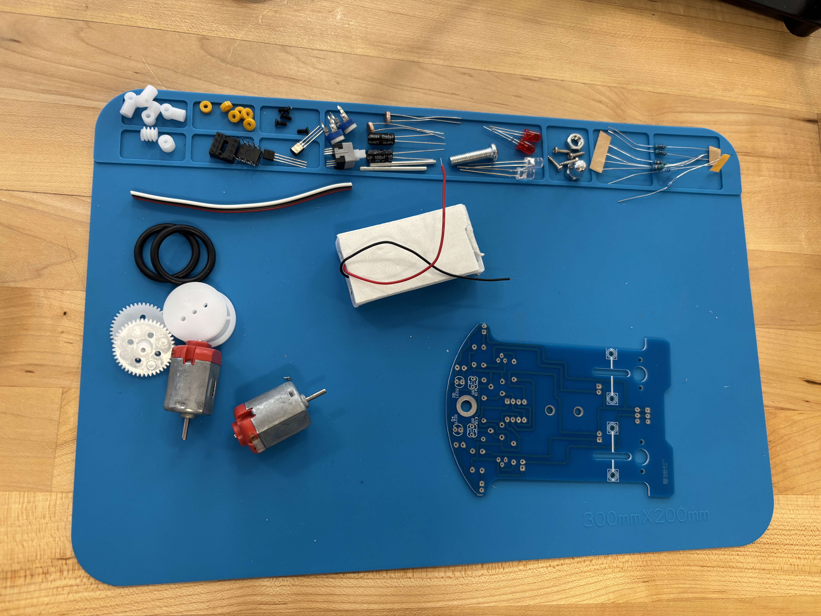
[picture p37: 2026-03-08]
assets/car_setup.jpeg

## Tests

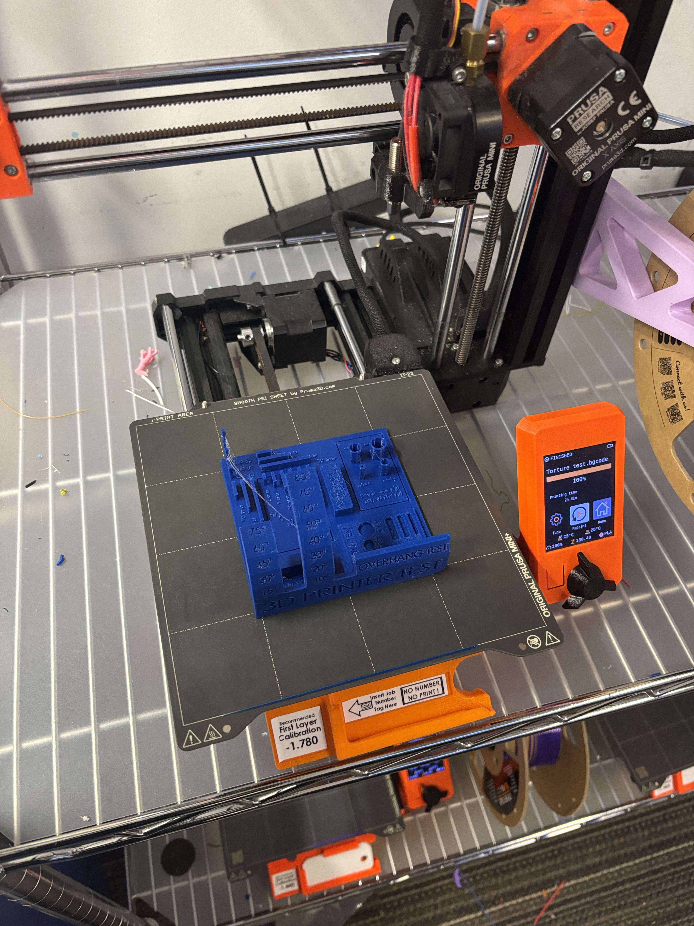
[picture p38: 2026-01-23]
assets/3D Torture Test_files/In_progress_torturetest.jpeg

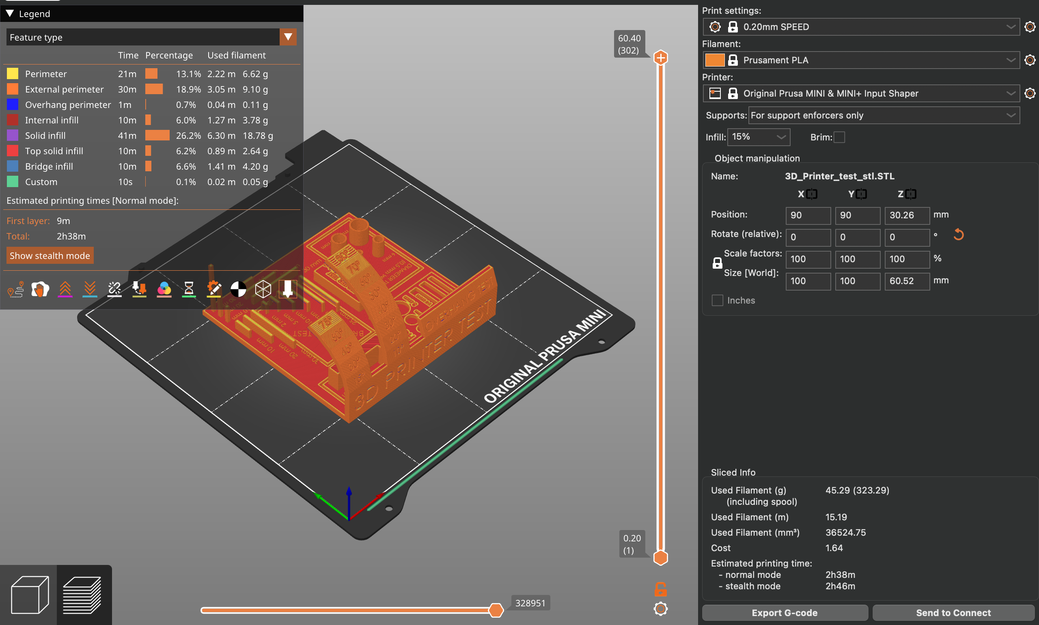
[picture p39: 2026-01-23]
assets/3D Torture Test_files/Setting_torturetest.png

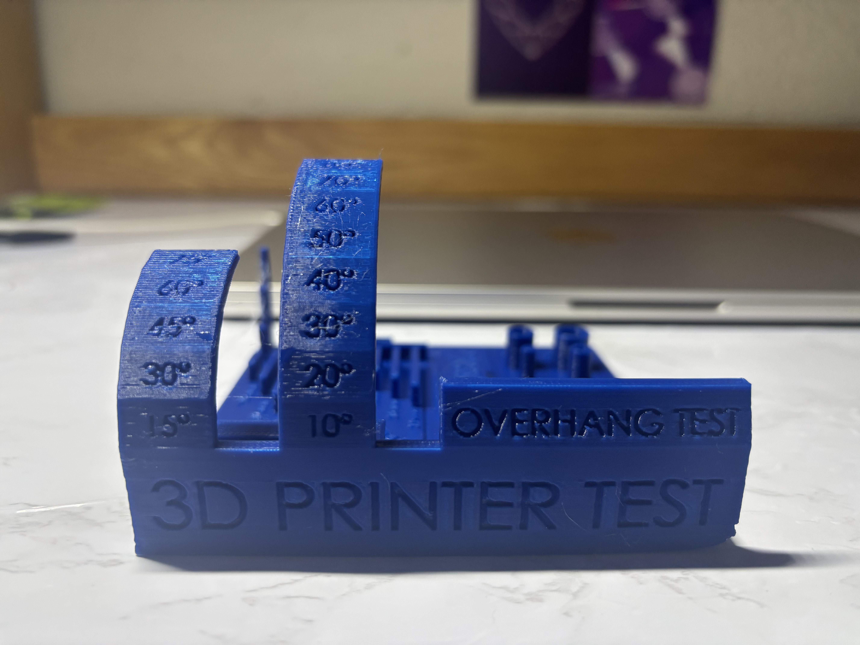
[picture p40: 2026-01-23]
assets/3D Torture Test_files/Torture_test.jpeg

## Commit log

2026-05-06 try
    Added detailed documentation for the One-Handed Shoe Tying Helper Device, including pictures, measurements, print settings, and links to instructions.
2026-05-06 Remove
    Removed detailed README content about the One-Handed Shoe Tying Helper Device, including images, measurements, and links.
2026-05-07 stl files
    [Rectangular box.stl, cycle 3 - Part 1 (1).stl, cycle 3 - Part 2.stl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]
2026-05-08 Enhance README with limitations and assembly steps
    Added notes on potential limitations and detailed step-by-step assembly instructions for the automatic pill dispenser project.
2026-05-08 Revise README instructions for battery connection and testing
    Updated instructions for connecting the battery and testing the system. Added clarifications on the Arduino IDE upload process and system behavior during testing.
2026-05-08 Replace image for Arduino connection instructions
    Updated image reference for Arduino IDE connection step.
2026-05-08 Enhance README with CAD steps and suggestions
    Added detailed steps for CAD design and suggestions for improvements.
